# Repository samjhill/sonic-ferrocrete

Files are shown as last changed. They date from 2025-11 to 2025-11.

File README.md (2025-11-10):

# Sonic Ferrocrete
### Sculpting cement with sound, magnetism, and open hardware




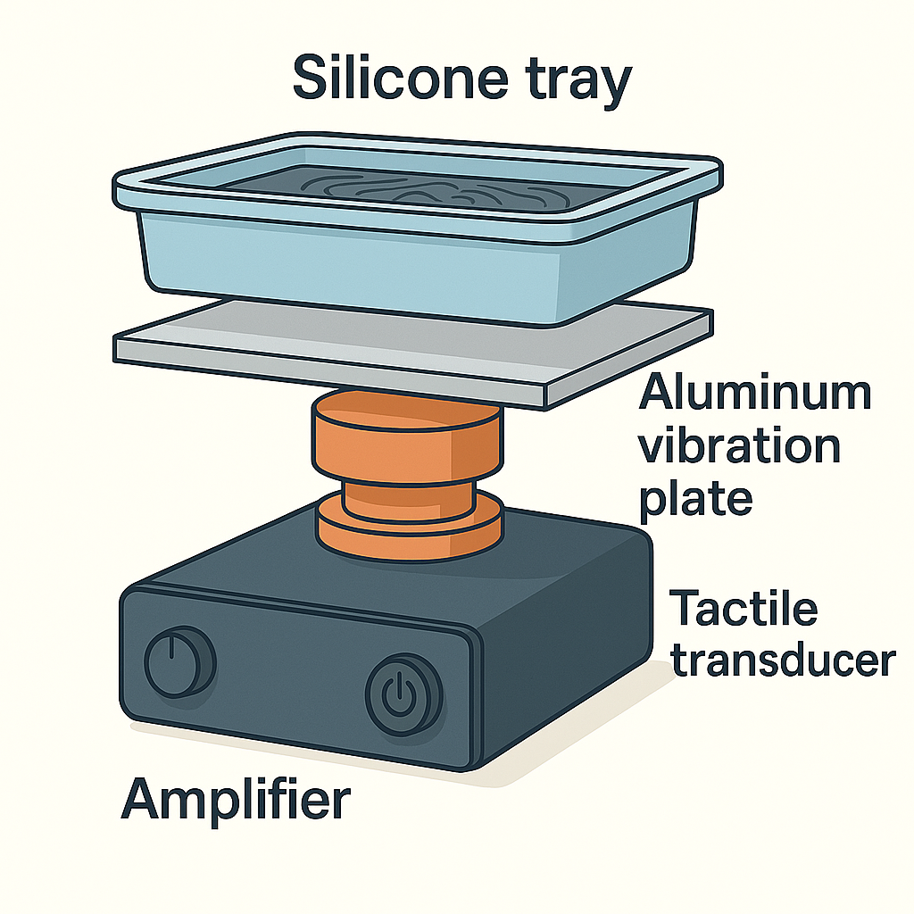
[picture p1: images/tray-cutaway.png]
Sonic ferrocrete tray and magnet sled assembly


> **Quick start (5 min):** Set up the tactile transducer under your tray, pour 5–8 mm Ultracal + Fe3O4 mix, sweep 70–200 Hz until steady cells appear, hold 6–10 min, cure, demold.

**Docs:** See `experiments/modeA_acoustic_patterning.md` and `experiments/modeB_magnetic_veining.md`  
**Contributing:** See `CONTRIBUTING.md` • **Citation:** `CITATION.cff`

Open, reproducible experiments in **magneto-acoustic forming** of gypsum/cement slurries (aka “sonic ferrocrete”).

**In plain language:** we’re playing with wet plaster and concrete mixes, shaking them with music-like tones, and nudging the iron particles inside with magnets. When the mix sets, you get ripples, veining, and textures that look like frozen sound waves or marble. If this works at scale, it’s a proof that you can *shape cement with waves*, hinting at future building elements cast with built-in acoustics, drainage, or ornament baked in from the first pour.

## Bench Snapshot

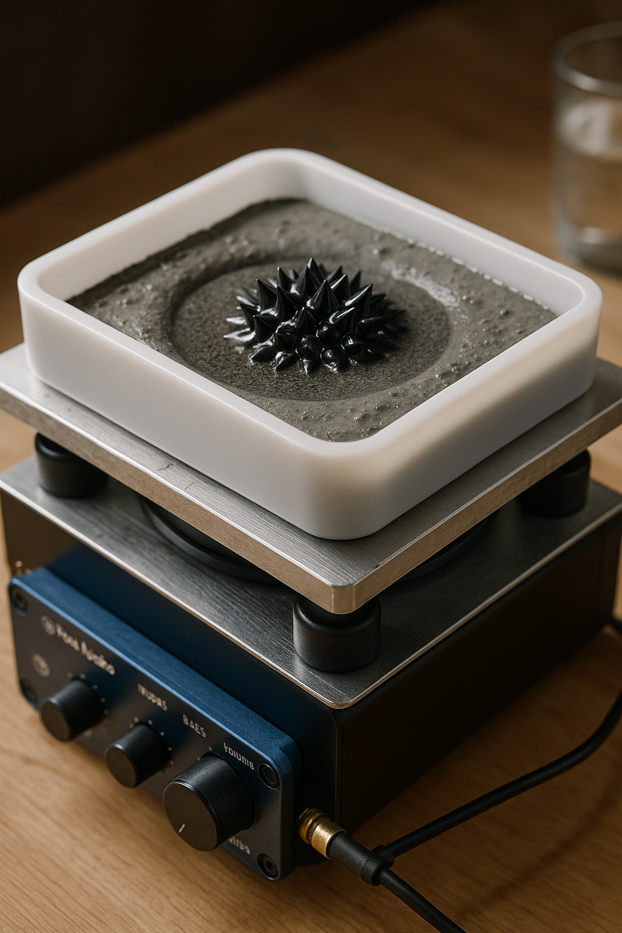
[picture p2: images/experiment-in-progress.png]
Experiment in progress

*Silicone mold riding on a tactile transducer during a live tone sweep.*

## TL;DR

- **What:** Open hardware + material recipes for sculpting cementitious mixes with sound, magnets, and electromagnets.
- **Who:** Makers, architects, materials researchers, and curious experimenters who want repeatable bench protocols.
- **Why:** Freeze standing waves and magnetic veining into panels to explore new building skins, art pieces, and responsive surfaces.
- **How:** Assemble the bench (transducer, tray, magnet sled), follow Mode A/B protocols, log results, and share back via the provided issue templates.

## Table of Contents

- [Bench Snapshot](#bench-snapshot)
- [What is this?](#what-is-this)
- [Getting Ready](#getting-ready)
- [Quick start](#quick-start)
- [Repo layout](#repo-layout)
- [First Milestone](#first-milestone)
- [Potential Applications](#potential-applications)
- [Safety](#safety)
- [Licensing](#licensing)
- [Contributing & Community](#contributing--community)

## What is this?

We embed magnetic particles (black iron oxide) in a fresh slurry and use **sound (standing waves)** and/or **magnetic fields** to organize surface topology and internal veining **before** the mix sets.

## Getting Ready

- Gear up with the [first-run shopping list](docs/SHOPPING_LIST.md) and optional [Amazon wishlist](https://www.amazon.com/hz/wishlist/ls/2M4MIQ3A0BSB9?ref_=wl_share).
- Review the full [experiment protocol & roadmap](docs/EXPERIMENT_PLAN.md) covering Modes A/B and future electromagnetic trials.
- Prep logging folders under `experiments/run_###/` so you’re ready to drop photos and CSVs immediately after a pour.

## Quick start

1. Assemble the tray and plate stack using `hardware/transducer_mounting.md`.
2. Follow `experiments/modeA_acoustic_patterning.md` (sound) and `modeB_magnetic_veining.md` (magnets).
3. Spin up `experiments/run_log_template.csv`, open an [Experiment Run issue](https://github.com/samjhill/sonic-ferrocrete/issues/new?template=experiment_run.yml), and capture photos per `experiments/photography_guide.md`.

## Repo layout

- `hardware/` — Magnet sled notes, BOM, mounting documentation for the bench hardware
- `experiments/` — lab guides (Mode A/B), photo tips
- `data/` — CSV templates for frequency/depth/viscosity vs. pattern results
- `simulation/` — thin-film heightfield notebook for rapid concept tests (`thinfilm_heightfield.ipynb`, open in Jupyter/VS Code; Binder link planned)
- `scripts/` — utilities (e.g., pixel-measurement to wavelength)

## First Milestone

- [ ] Print 120×120 tray; seal corners.
- [ ] Water resonance dry-run (Hz vs. visible cell count).
- [ ] Mode A: 3 freqs × 2 depths → photos + CSV.
- [ ] Mode B: straight-line + spiral sled → photos.
- [ ] Short video; share repo link.

## Potential Applications

### Cymatic Architectural Facade
 Frozen ripples create a sound-shaped facade module for large-scale installations.
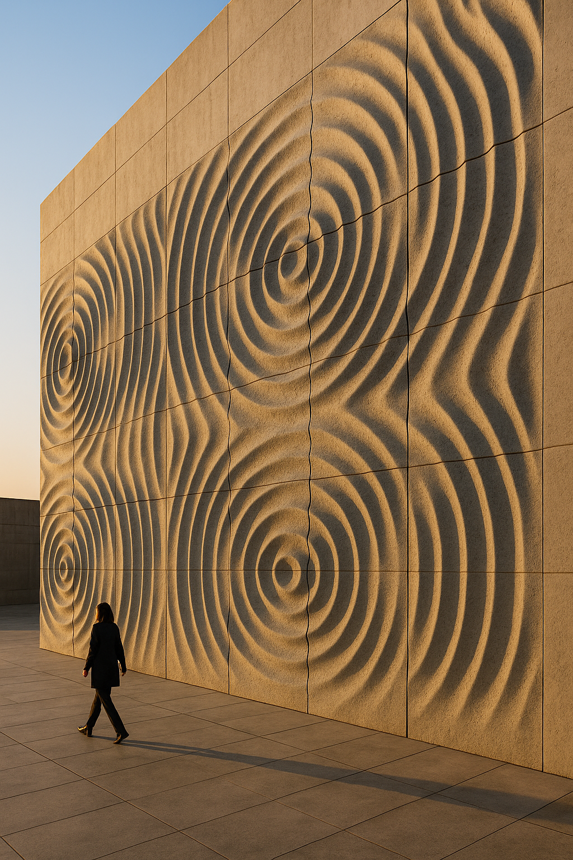
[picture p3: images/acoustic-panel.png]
Cymatic architectural facade concept

*Concept render: acoustic standing waves cast into facade panels.*

### Magnetically Veined Plaster Panel
Magnetite veining suggests marble-like surfaces guided by field lines.
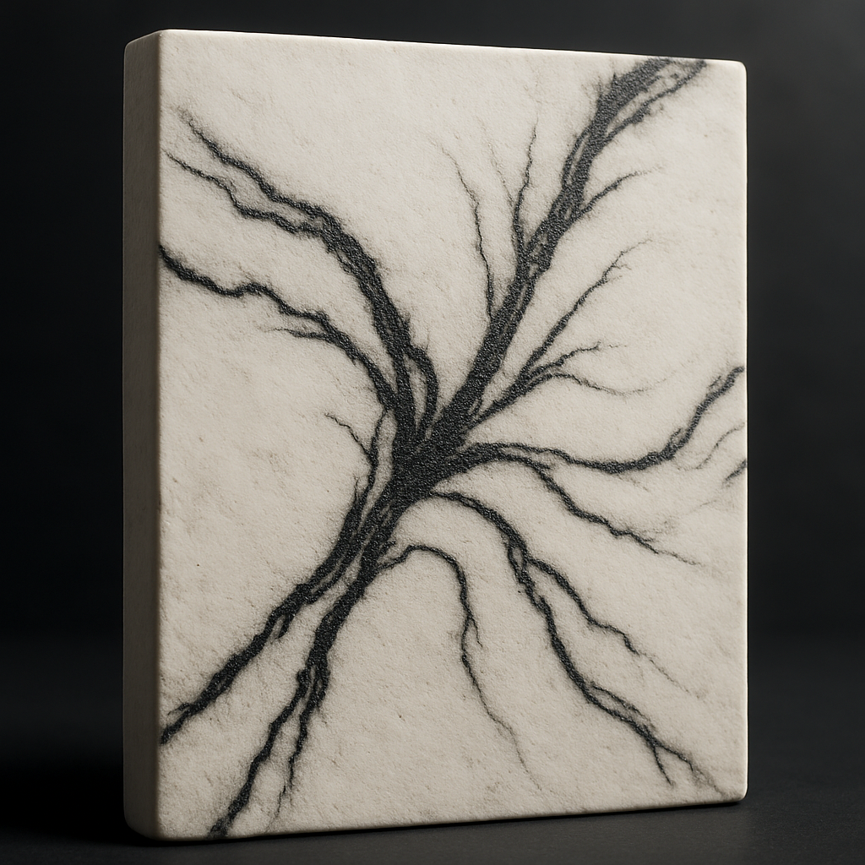
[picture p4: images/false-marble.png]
Magnetically veined plaster concept

*Concept render: magnetite-rich veins emulate marble textures.*

### Sound-formed Sculpture
Mid-resonance waves solidify into sculptural geometry—dynamic motion caught in time.
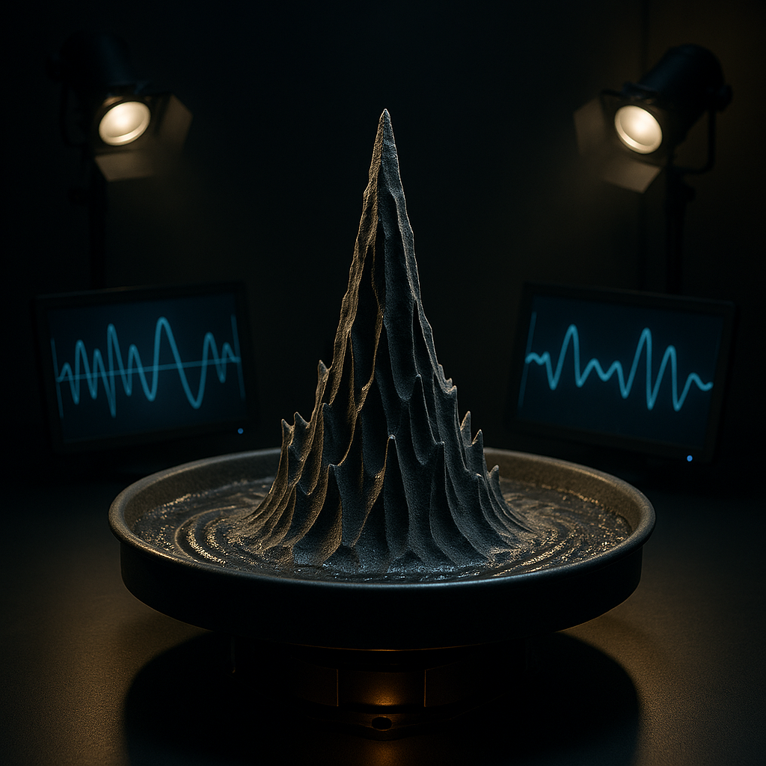
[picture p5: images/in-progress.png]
Sound-formed sculpture concept

*Concept render: resonant ridges captured mid-pour.*

### Bio-reactive Concrete Facade
Porous, patterned surfaces encourage moss and lichen colonization while managing moisture.
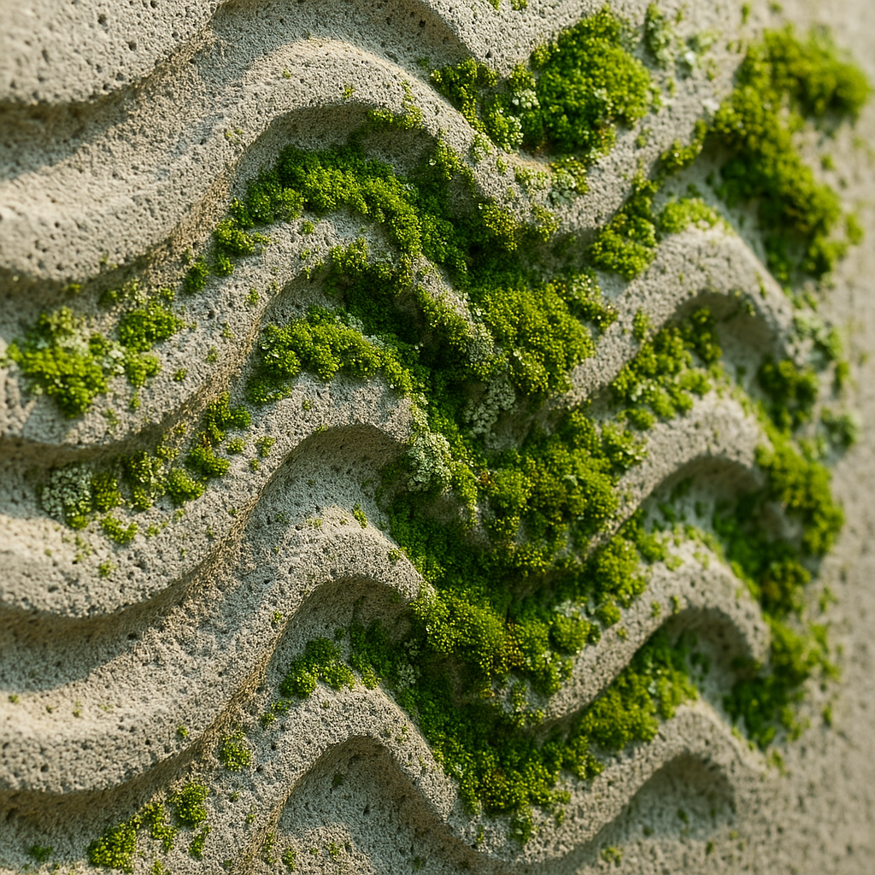
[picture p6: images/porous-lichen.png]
Bio-reactive concrete facade concept

*Concept render: sound-shaped cavities support moss/lichen growth.*

### Pavilion Formed by Sound
Large-scale intervention shaped by resonance patterns for immersive environments.
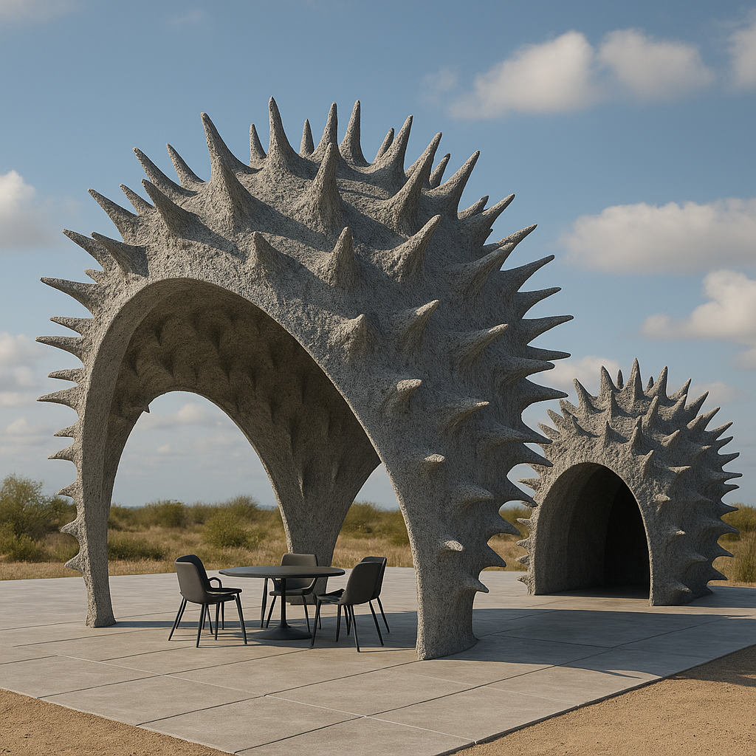
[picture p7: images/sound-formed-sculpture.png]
Sound-shaped pavilion concept

*Concept render: pavilion surfaces derived from sonic interference.*

## Safety

- Wear hearing protection when running prolonged tone sweeps.
- Use N95/P100 masks and gloves while handling cement, iron oxide, or sand.
- Keep strong magnets away from electronics, cards, and pinch points.
- Follow the detailed cautions in the experiment docs before mixing or casting.

## Licensing

- Code, CAD, and scripts: [MIT License](LICENSE)
- Media (photos/figures/renders): [CC BY 4.0](https://creativecommons.org/licenses/by/4.0/) — attribute “Sonic Ferrocrete / Sam Hill”

## Contributing & Community

- Start with the [CONTRIBUTING guide](CONTRIBUTING.md) and the [Code of Conduct](CODE_OF_CONDUCT.md).
- Log each pour with the [Experiment Run issue template](https://github.com/samjhill/sonic-ferrocrete/issues/new?template=experiment_run.yml) and attach data/photos in `experiments/run_###/`.
- Share tweaks to `hardware/*.scad` with screenshots or STL artifacts; the CI workflow auto-exports tray/sled STLs on PRs.
- Discuss ideas, request features, or ask questions by opening an issue labeled `question` or `planning`.

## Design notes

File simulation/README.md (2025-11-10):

# Simulation Notes

- This is a qualitative height-field model to explore pattern control (not a CFD).
- Use it to choose combinations of frequencies and magnet layouts before pouring.

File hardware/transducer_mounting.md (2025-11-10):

# Transducer Mounting Notes

A repeatable clamp-up between the TT25 (or future BST-1) and the aluminum drive plate keeps energy transfer high and lets you swap plates without tearing epoxy. The workflow below uses reversible components so you can tune the stack quickly.

## Bill of mounting parts

- 3M VHB LSE 110WF tape (25 mm wide) **or** thin layer of Loctite Clover coupling compound
- 1 mm neoprene or sorbothane pad (cut to 60 mm disc) for isolation feet
- Laser-cut/printed collar or four 20 mm corner clamps
- M5 × 35 mm socket cap screws (x4) with wing nuts or thumb nuts
- M5 washers (x8) to protect plate surface
- Optional: 90° toggle clamps (short reach) if you prefer a quick-release mechanism

## Assembly procedure

1. **Prep surfaces:** Clean the aluminum plate and the TT25 puck with isopropyl alcohol. Lightly scuff the puck’s mating face with fine Scotch-Brite for extra grip, then wipe again.
2. **Apply coupling layer:**
   - For VHB tape: cut a 50 mm circle, press onto the puck, then peel the top liner right before mounting.
   - For Clover compound: spread a paper-thin film on the puck using a plastic card. Aim for full coverage without squeeze-out.
3. **Seat the transducer:** Center the TT25 on the underside of the plate. If using VHB, apply firm, even pressure for 30–60 s. For grease, gently twist to break any air pockets.
4. **Clamp:** Place the printed collar or four corner clamps around the puck. Feed M5 screws through the collar into captive nuts/wing nuts above the plate. Tighten gradually in a cross pattern until snug. Do not overtighten; you just need intimate contact.
5. **Add isolation feet:** Adhere rubber isolation pads or sorbothane discs to the bottom of the plate corners. Ensure equal thickness so the tray sits level.
6. **Route wiring:** Zip-tie the transducer leads to one leg of the collar so the cable can’t tug on the puck during sweeps.
7. **Swap plates:** To remove the puck, loosen the clamps, peel the VHB or wipe away coupling compound, and clean surfaces with IPA. Keep spare VHB circles pre-cut for quick changeovers.

## Tips

- Re-check clamp tension after long high-amplitude sweeps—the coupling layer can creep as the plate warms.
- If you upgrade to a BST-1, print a deeper collar: leave 2–3 mm radial clearance and extend screw length to M6 × 45 mm.
- Mark the resonant axes on the plate once identified; aligning the tray with these marks speeds repeatability.
- Keep dedicated “clean” and “messy” plates to avoid cross-contamination of coupling grease and cement slurry.

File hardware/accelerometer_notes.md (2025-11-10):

# Plate Accelerometer Notes

Measuring tray acceleration lets you correlate ripple quality with actual drive levels instead of relying only on amplifier gain. A small MEMS breakout mounted to the aluminum plate gives you 3-axis data suitable for FFT analysis.

## Recommended sensor options

- **Adafruit LIS3DH breakout** (I²C/SPI, ±16 g range, 100–400 Hz output). Stable, easy to integrate with CircuitPython or Arduino.
- **Analog Devices ADXL335 module** (analog outputs, ±3 g). Simple to read with a microcontroller ADC if you prefer analog processing.
- **Upgrade path:** Analog Devices ADXL355 or TE 4030 for lower noise when you scale up; requires more advanced data acquisition.

## Companion microcontroller/data logger

- ESP32 DevKitC or Feather (built-in USB, Wi-Fi for streaming).
- Teensy 4.0 or Arduino Nano Every if you want higher sample rates with wired logging.
- MicroSD breakout (optional) if you want stand-alone logging to card.

## Mounting approach

1. Cut a 25 mm square of thin VHB or reusable poster putty.
2. Clean a corner of the aluminum plate with IPA.
3. Bond the accelerometer board flat to the plate surface—ideally near an antinode but away from the slurry tray footprint.
4. Strain-relief the wires using Kapton or cloth tape so they don’t tug during sweeps.
5. Note the sensor orientation (X/Y/Z axes) directly on the plate with a marker for repeatability.

## Data capture workflow

- Configure the LIS3DH at 200 Hz ODR, ±8 g range. Stream XYZ via USB serial to a laptop running a Python logger (e.g., `examples/accelerometer_logger.py` to be added). Convert to RMS acceleration and frequency spectrum in post-processing.
- For ADXL335, sample at ≥1 kHz on three ADC pins, apply a simple moving-average filter, and compute FFT in Python or on-board if using a Teensy.
- Sync data with audio sweeps by printing timestamps/frequency steps to the same log.

## Calibration

- Perform a 6-point calibration (±1 g on each axis) or use a simple one-axis static calibration by orienting the sensor along gravity and recording offset.
- Run a baseline measurement with the shaker off to capture noise floor.
- Map plate acceleration vs. amplifier gain at a handful of frequencies (e.g., 80, 120, 160 Hz) and store the curves in `data/` for future reference.

## Safety & durability

- Secure all wiring so nothing can whip into the wet tray.
- Keep the microcontroller and laptop elevated or shielded from splashes.
- If you switch to the BST-1, revisit mounting: use a thin aluminum bar to triangulate the accelerometer mount and reduce local strain on the plate.

Add derived datasets (`*.csv`) under `data/plate_characterization/` once you capture the first sweeps.

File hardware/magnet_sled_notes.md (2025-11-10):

# Magnet Sled Notes

- Fits under-tray rails; slide slowly, pause 10–30 s to “draw” magnetite ribs.
- Slot sized for 60×10×3 mm bars; stack bars for stronger gradients.
- Keep at least ~3–5 mm between magnets and tray floor to avoid sticking/slamming.

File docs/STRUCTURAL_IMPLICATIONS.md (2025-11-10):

# Sonic Ferrocrete Structural Implications

This note tracks early thinking on how sonic- and magnet-shaped cementitious mixes could translate into structural or envelope gains. Treat it as a living document—add back-of-envelope calculations, test results, and literature references as the project evolves.

## 1. Target Applications

- **Lightweight facade panels:** Built-in ribs/grooves for stiffness, drainage, and acoustic diffusion.
- **Shell structures:** Sound-shaped curvature to distribute loads (arches, domes, vaulted roofs).
- **Core-and-skin walls:** Sonic Ferrocrete skin bonded to conventional structural core (reinforced concrete, light-gauge steel).
- **Site-cast slabs:** Rippled slabs or stairs for traction and reduced material usage.

## 2. Pattern → Performance Hypotheses

| Pattern Type | Potential Benefit | Notes / Metrics to Track |
|---|---|---|
| Standing-wave ribs (1D) | Increase bending stiffness with minimal material | Measure section modulus vs. flat panel |
| Hexagonal/“cell” patterns | Distribute loads isotropically; aesthetic texture | Finite-element comparison of stress distribution |
| Magnetite veining | Add localized reinforcement or EM shielding | Analyze shear strength, conductivity, corrosion behavior |
| Gradient relief | Redirect water, enhance acoustic diffusion | Test water shedding (drainage rate), acoustic absorption |

## 3. Structural Considerations

- **Rheology window:** Structural patterns require predictable working time to avoid slump. Log yield stress, plastic viscosity, and gel time for each mix.
- **Pattern depth vs. thickness:** Document ratios (relief depth / panel thickness) that preserve strength. Start with 5–10 mm relief on 20–25 mm panels.
- **Bonding to reinforcement:** Explore how magnetite alignments interact with rebar or mesh; avoid isolating reinforcement from bulk matrix.
- **Thermal movement:** Relief patterns may concentrate shrinkage or expansion stresses—monitor for crack initiation around nodes.
- **Fire performance:** Map how voids or cavities affect heat transfer and spalling risk.

## 4. Test Matrix (Draft)

| Sample | Mix | Pattern | Reinforcement | Tests |
|---|-----|---|---|---|
| Panel A | Ultracal baseline | Flat (control) | None | Flexural strength, surface hardness |
| Panel B | Ultracal + magnetite | 120 Hz ripple | None | Flexural, shear, imaging of magnetite bands |
| Panel C | UHPC concept | 90 Hz ripple + magnet veining | GFRP mesh | Flexural, tensile pull-off, freeze–thaw |
| Panel D | Future | Gradient relief | Steel mesh | Thermal cycling, drainage rate |

## 5. Analysis Tools

- Finite-element tools (e.g., Fusion 360, ANSYS, or Grasshopper/Karamba) to simulate patterned plates.
- Digital image correlation for strain mapping (long-term goal).
- Microscope/CT scans to visualize magnetite distribution.

## 6. Open Questions

- What relief amplitudes deliver meaningful stiffness gains without compromising durability?
- How does magnetite concentration affect rebar corrosion or electromagnetic properties?
- Can patterned surfaces reduce cladding weight enough to offset actuation energy costs?
- What building code pathways exist for adopting patterned panels (e.g., ICC-ES reports, ASTM testing)?

## 7. Next Actions

- [ ] Gather literature on ribbed concrete panels and bio-inspired shell structures.
- [ ] Design simple FEA study comparing flat vs. ripple panels.
- [ ] Plan mechanical testing protocol for first patterned slabs (fixtures, load setup).
- [ ] Capture high-resolution surface scans of Mode A/B specimens for analysis.

_Add ideas, sketches, or references here as the project advances._

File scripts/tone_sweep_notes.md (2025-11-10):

Use a phone tone-generator app. Sweep 50–250 Hz slowly. Note frequencies yielding stable cells. Keep volume modest; aim for visible ripples, not splashing.

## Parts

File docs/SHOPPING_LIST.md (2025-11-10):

# First-Run Shopping List

| Item | Notes | Price* | Delivery |
|---|---|---|---|
| 2× 6061-T6 aluminum sheet, 6"×6"×0.236" (ZOFORTY) | Polished, deburred plate for transducer deck | $17.99 | Overnight (4–8 AM) |
| 2× 7"×5" silicone tray molds (SXYYDSG) | Silicone liners for slurry | $12.49 (5% coupon applied) | — |
| 8× rubber isolation pads, 1.5" OD (Treela) | Damp vibration from plate to bench | $9.99 | FREE One-Day |
| NOW Foods xanthan gum, 6 oz | Rheology modifier for slurry | $6.50 | Today (10 AM–3 PM) |
| Dayton Audio TT25-8 tactile transducer | Primary driver for standing waves | $17.98 | FREE One-Day |
| Ultracal 30 gypsum cement, 10 lb | Primary casting material | $35.89 | FREE One-Day |
| Fosi Audio TB10D amplifier (TPA3255) | Power for transducer | $67.99 (15% off) | Overnight (4–8 AM) |
| 24× neodymium bar magnets, 60×10×3 mm (LOVIMAG) | Magnet sled inserts for Mode B | $18.98 | Overnight (4–8 AM) |
| Alpha Pro dry superplasticizer, 1 lb | Reduce water demand | $29.99 | — |
| White quartz sand, 40–80 mesh, 2 lb (AOSWTLIF) | Optional filler / texture | $13.99 (coupon to $13.29) | Overnight (4–8 AM) |
| Black iron oxide pigment, 500 g (T-MILES) | Magnetite source for veining | — | — |
| 3M VHB LSE 110WF double-sided tape (1"×5 yd) | Removable bond between puck and plate | $28.27 | — |
| 3M 8511 N95 respirators, 10-pack | Dust protection during mixing | $16.99 | Today (5–10 PM) |
| Etekcity 774 IR thermometer | Monitor plate/surface temps | $18.99 | Today (5–10 PM) |
| BOMATA 0.1 g precision scale (5 kg) | Weigh mixes and admixtures | $33.88 | Today (5–10 PM) |
| Amazon Basics 3.5 mm to RCA cable, 4 ft | Connect tone source to amplifier | $7.55 | Today (5–10 PM) |
| 50-pack 3 mL LDPE transfer pipettes | Spot-dose water, admixtures, or pigments | $8.99 | — |
| Loctite Clover grinding & lapping compound, 2 oz | Thin coupling layer between puck and plate | — | — |
| Adafruit LIS3DH accelerometer breakout | Plate vibration sensing (I²C) | $14.95 | — |
| ESP32 DevKitC (USB-C) | Streams accelerometer data | $9.99 | — |
| MicroSD logger breakout + 32 GB card | Optional onboard data storage | $12.99 | — |
| Kapton tape roll (1/2") | Strain relief & insulation for sensor leads | $6.49 | — |
| KEYFANCLUB dual 120 mm fan module | Cooling for electronics and coil experiments | $23.99 | — |

\*Prices captured November 10, 2025. Check current listings before purchase.

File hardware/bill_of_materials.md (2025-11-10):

## Core

- Ultracal 30 (10 lb)
- Black iron oxide (Fe3O4) ~500 g
- Xanthan gum (food grade) 6 oz
- Superplasticizer (polycarboxylate), ~1 lb
- Fine sand 40–80 mesh (optional)

## Acoustics

- Fosi TB10D (TPA3255) + included PSU
- Dayton TT25-8 tactile transducer (×1; optional ×2 for later)
- 3.5 mm → RCA cable; rubber feet; epoxy (transducer mount)

## Magnetics

- Neodymium bar magnets 60×10×3 mm (pack of 24)

## Fabrication

- PETG/ABS for tray or machine from acrylic/aluminum
- Silicone sealant (thin bead at tray corners)
- 3M VHB LSE tape or epoxy for temporary transducer bonding
- Thin coupling compound (e.g., Loctite Clover 2 oz) for shaker-to-plate interface
- Printed collar or corner clamps + M5 hardware for transducer mounting
- Neoprene/sorbothane pads for isolation feet

## Instrumentation

- LIS3DH/ADXL335 accelerometer breakout (plate vibration logging)
- ESP32 DevKit or Arduino Nano + USB cable (sensor interface)
- MicroSD logger or laptop capture script
- Kapton tape or VHB tabs for sensor mounting/strain relief
- 120 mm dual-fan module (e.g., KEYFANCLUB Dual 120 mm) for cooling electronics during longer runs

## Lab & Safety

- Disposable LDPE transfer pipettes (3–5 mL pack)
- Nitrile gloves, respirator, and safety glasses/ear protection for mixing

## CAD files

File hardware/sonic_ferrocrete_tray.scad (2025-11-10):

// Sonic-Ferrocrete Bench Tray + Magnet Sled (Parametric)

// Units: mm

// Usage: tweak "User Parameters", F6 (Render), then export STL.

tray_len = 120;  // inner X (liquid)
tray_wid = 120;  // inner Y
wall_h   = 12;
wall_t   = 4;
floor_t  = 4;
corner_r = 4;

lip_t = 2; lip_h = 2; add_lip = true;

// Feet

feet_d = 10; feet_h = 5; feet_inset = 8;

// Transducer bolt circle (set mount_enable=false if epoxying puck)

mount_enable=true; mount_holes=4; mount_bc_diam=30; mount_hole_d=3.2;

mount_center_offset=[0,0];

// Under-tray magnet rails

rails_enable=true; rail_w=12; rail_h=3; rail_gap=30; rail_inset_y=12;

// Magnet sled (printed separately)

sled_len = tray_len + 2*wall_t + 20;

sled_wid = rail_gap + 2*rail_w - 0.6;

sled_h = rail_h + 2; sled_handle_h=20;

mag_slot_len = tray_len; mag_slot_wid=18; mag_slot_d=4;

// Draft for inner walls

draft_deg=2;

module filleted_box_xy(size=[20,20,10], r=2){

  translate([r,r,0])

  minkowski(){ cube([size[0]-2*r,size[1]-2*r,size[2]-0.001]);

               cylinder(r=r,h=0.001,$fn=32); }

}

module drafted_tray(inner=[100,100], wall=4,h=12,floor=4,r=3,draft_deg=2){

  outer=[inner[0]+2*wall, inner[1]+2*wall, floor+h];

  difference(){

    filleted_box_xy(outer,r=r);

    translate([wall,wall,floor])

    linear_extrude(height=h+0.1,

      scale=1 + 2*wall * tan(draft_deg/180*3.14159) / inner[0])

    offset(r=-r) square([inner[0],inner[1]]);

    if(mount_enable)

      for(i=[0:mount_holes-1]){

        angle=360/mount_holes*i;

        x=mount_center_offset[0]+(mount_bc_diam/2)*cos(angle);

        y=mount_center_offset[1]+(mount_bc_diam/2)*sin(angle);

        translate([outer[0]/2+x, outer[1]/2+y, 0])

          cylinder(d=mount_hole_d,h=floor+1,$fn=24);

      }

    if(rails_enable){

      outerX=outer[0]; outerY=outer[1];

      rail_total_w=2*rail_w+rail_gap;

      rail_start=rail_inset_y; rail_end=outerY-rail_inset_y;

      translate([(outerX-rail_total_w)/2, rail_start, 0])

        cube([rail_w, rail_end-rail_start, rail_h]);

      translate([(outerX-rail_total_w)/2+rail_w+rail_gap, rail_start, 0])

        cube([rail_w, rail_end-rail_start, rail_h]);

    }

  }

}

module add_lip(outer=[120,120,18],wall=4,lip_t=2,lip_h=2,r=3){

  translate([0,0,outer[2]-lip_h])

  difference(){

    filleted_box_xy([outer[0]+2*lip_t, outer[1]+2*lip_t, lip_h], r=r);

    translate([lip_t,lip_t,-0.1])

      filleted_box_xy([outer[0],outer[1],lip_h+0.2], r=max(r-0.8,0.5));

  }

}

module feet_posts(outer=[120,120,18],d=10,h=5,inset=8){

  for(sx=[inset, outer[0]-inset])

  for(sy=[inset, outer[1]-inset])

    translate([sx,sy,0]) cylinder(d=d,h=h,$fn=30);

}

module tray_assembly(){

  outer=[tray_len+2*wall_t, tray_wid+2*wall_t, floor_t+wall_h];

  drafted_tray([tray_len,tray_wid], wall_t, wall_h, floor_t, corner_r, draft_deg);

  feet_posts(outer,feet_d,feet_h,feet_inset);

  if(add_lip) add_lip(outer,wall_t,lip_t,lip_h,corner_r);

}

module magnet_sled(){

  outer=[tray_len+2*wall_t, tray_wid+2*wall_t, floor_t+wall_h];

  sledX=sled_len; sledY=rail_gap+2*rail_w-0.6;

  difference(){

    translate([(outer[0]-sledX)/2,(outer[1]-sledY)/2,-sled_h])

      cube([sledX,sledY,sled_h]);

    translate([(outer[0]-mag_slot_len)/2,(outer[1]-mag_slot_wid)/2,-sled_h-0.1])

      cube([mag_slot_len,mag_slot_wid,mag_slot_d]);

  }

  translate([outer[0]/2-30,(outer[1]-sledY)/2 + sledY/2 - 2,-sled_h])

    cube([60,4,sled_handle_h]);

}

$fn=64;

// Uncomment to export:

// tray_assembly();

// magnet_sled();

// Preview:

translate([0,0,0]) tray_assembly();

translate([0, tray_wid + 2*wall_t + 20, 0]) magnet_sled();

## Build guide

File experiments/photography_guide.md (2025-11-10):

# Photography

- Top-down timelapse (1–2 s interval).
- Raking light at 20–30° to emphasize relief.
- Include a ruler in one frame for pixel→mm scale.

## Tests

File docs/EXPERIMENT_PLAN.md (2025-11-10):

# Sonic Ferrocrete Experiment Protocol

## Overview

This document outlines the experimental procedure, material recipes, and development roadmap for manipulating cement-based composites using sound, magnetism, and electromagnetism. The goal is to explore patterned and magnetically veined castings for architectural, artistic, and structural applications.

---

## Phase 1 – Acoustic Patterning (Mode A)

### Objective

Generate and freeze cymatic standing-wave patterns in a cement or Ultracal 30 slurry using vibration.

### Setup

- Aluminum plate (150×150×6 mm) with tactile transducer (Dayton TT25-8) bonded to its underside.
- Silicone tray (7×5 in or 120×120 mm) seated on top of plate.
- Plate mounted on four rubber isolation pads.
- Fosi Audio TB10D amplifier connected to a tone generator.

### Mix

| Ingredient | Amount | Notes |
|---|---|---|
| Ultracal 30 | 100 g | Base gypsum cement |
| Fe₃O₄ (magnetite) | 10–20 g | Adds magnetic contrast |
| Water | 70–75 g | Water-to-binder ratio 0.7–0.75 |
| Alpha Pro superplasticizer | 0.2–0.3 g | Reduces water need |
| Xanthan gum | 0.08–0.12 g | Adds thixotropy |

Depth: 4–8 mm per pour.

### Procedure

1. Mix slurry until smooth and lump-free.  
2. Pour into tray (depth 6 mm).  
3. Start a sine sweep from 40–400 Hz.  
4. Watch for stationary node patterns; hold at resonant frequency.  
5. Capture top/side photos and videos.  
6. Record frequency, amplitude, and mix ratios.

---

## Phase 2 – Magnetic Veining (Mode B)

### Objective

Introduce veined patterns by migrating magnetite particles along magnetic field lines.

### Setup

- Add a **magnet sled** (neodymium bars, 60×10×3 mm) sliding under plate.  
- Maintain ≥25 mm gap from transducer.  
- Use the same tray and mix, slightly thicker (higher xanthan).

### Procedure

1. Start vibration at previously determined resonant frequency.  
2. Move magnet sled slowly (1–5 mm/s).  
3. Pause sled under tray for 10–30 s to form visible veins.  
4. Stop vibration, allow to set.  
5. Document position and shape of magnetite veining.

---

## Phase 3 – Electromagnetic Control

### Objective

Add an adjustable DC magnetic field to bias magnetite migration.

### Recommended Coil

- Pancake coil: 100–200 turns of 20 AWG magnet wire, 120–150 mm diameter.  
- Drive: 0–2 A constant current, 12–24 V supply.  
- Mounted below the aluminum plate (or under acrylic window).  
- Use **DC only** to avoid eddy losses in aluminum.

### Procedure

1. Run acoustic patterning as before.  
2. Slowly ramp coil current (0.1–1.0 A).  
3. Record pattern shape changes vs. current.  
4. Repeat trials for reproducibility.

---

## Measurements & Data Logging

| Parameter | How to Measure | Purpose |
|---|---|---|
| Frequency & amplitude | Oscilloscope or software | Acoustic tuning |
| Plate acceleration | IMU or accelerometer | Quantify vibration |
| Pattern geometry | Photo/video | Qualitative comparison |
| Magnetic field strength | Hall sensor | Field mapping |
| Mix parameters | Weight scale | Repeatability |

Save all photos and data under `/experiments/run_###/`.

---

## Troubleshooting

| Issue | Likely Cause | Fix |
|---|---|-----|
| No visible pattern | Poor coupling or too deep pour | Reduce depth or retighten plate |
| Pattern blurs | Slurry too thin | Increase xanthan or wait partial set |
| Magnetite clumps | Too viscous | Reduce xanthan slightly |
| Amp clips | Volume too high | Lower gain or add subsonic filter |
| Weak veining | Magnet distance too large | Move closer or use stronger bars |

---

## Roadmap

| Phase | Goal | Estimated Duration |
|---|---|---|
| 1 | Stable cymatic patterns | 1 week |
| 2 | Controlled magnetic veining | 1–2 weeks |
| 3 | Active electromagnetic control | 2–4 weeks |
| 4 | Scaled molds & composite testing | 1–2 months |

---

## Safety

- Wear eye & hearing protection.
- Avoid placing magnets near amplifier or transducer.
- Use PPE when handling cement and iron oxide.
- Maintain ventilation during mixing and casting.

---

## Next Steps

- Automate frequency sweeps and logging (Python script).  
- Design printable tray master (STL) for making silicone liners.  
- Experiment with lightweight “aircrete” backfill.  
- Publish open-source datasets and results under `/data/`.

---

© 2025 Hillside Innovations – Open Hardware & Material Research

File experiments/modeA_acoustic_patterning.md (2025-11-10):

# Mode A — Acoustic Patterning (Bench Protocol)

## Mix (by weight)

- 100 g Ultracal 30
- 15 g black iron oxide (15%)
- 70–75 g water (w/s ≈ 0.70–0.75)
- 0.3 g superplasticizer (0.3% of binder)
- 0.08 g xanthan (0.08%) — tiny

## Steps

1. Dry-run with WATER @ depth 5–8 mm. Sweep **70–200 Hz**; note stable ripples.
2. Mix slurry: pre-disperse oxide in water → add admixtures → sift in Ultracal (30–45 s stir).
3. Pour to 5–8 mm depth; pop bubbles with light IPA mist.
4. Start chosen frequency at low gain; increase until steady ripples appear (no slosh).
5. Hold ~6–10 min until surface loses sheen and motion “freezes”.
6. Stop audio; cure 30–60 min; demold.
7. Log frequency, amplitude setting, depth, time-to-gel. Photograph with raking light.

**Troubleshooting**

- No pattern: reduce depth to 3–5 mm; sweep slower; +superplasticizer.
- Wash-out: reduce amplitude; shorten working time.
- Settling: +xanthan slightly; remobilize with gentle tap before tone.

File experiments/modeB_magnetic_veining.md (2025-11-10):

# Mode B — Magnetic Veining

1. Pour same base mix; no tone first.
2. Slide magnet sled under tray in lines/spirals; **pause 10–30 s** where darker ribs desired.
3. Park magnets during gel (~5–10 min), then remove.
4. Optional: low-level tone during painting to keep fines mobile.
5. Cure & demold; photograph.

**Success:** visible dark filaments; sometimes slight raised relief.

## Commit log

2025-11-10 init: sonic-ferrocrete open starter
    [frequency_vs_wavelength.csv, run_log_template.csv, sonic_ferrocrete_tray.scad]
2025-11-10 ci: add OpenSCAD STL build workflow
2025-11-10 docs: expand shopping list with gear and instrumentation
2025-11-10 docs: add pipettes and safety gear to prep lists
2025-11-10 docs: refresh tray assembly illustration
2025-11-10 docs: note clover compound for coupling
2025-11-10 hardware: document transducer mounting scheme
2025-11-10 hardware: outline accelerometer instrumentation
2025-11-10 hardware: add dual fan module to prep lists
2025-11-10 docs: tighten plain-language intro

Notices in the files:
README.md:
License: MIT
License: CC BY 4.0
